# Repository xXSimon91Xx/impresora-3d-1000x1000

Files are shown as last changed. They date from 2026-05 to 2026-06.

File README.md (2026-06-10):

<p align="center">
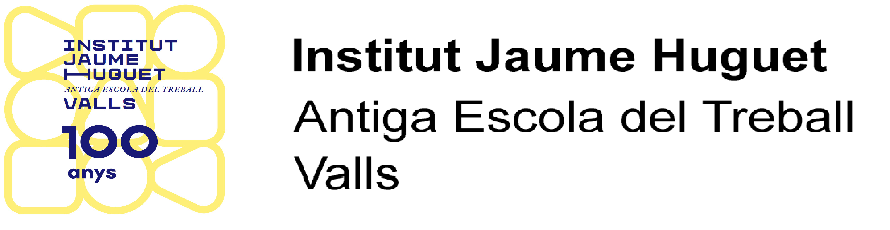
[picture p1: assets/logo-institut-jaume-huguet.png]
Institut Jaume Huguet — Antiga Escola del Treball, Valls
  
</p>

<h1 align="center">Impresora 3D Cartesiana 1000×1000×1000 mm</h1>

<p align="center">
  <strong>Cicle Formatiu de Fabricació Additiva — CEFP 2025-2026</strong><br>
  <strong>Institut Jaume Huguet — Antiga Escola del Treball</strong>, Valls (Tarragona)<br>
  <a href="https://institutjaumehuguet.cat">institutjaumehuguet.cat</a>
</p>

<p align="center">
  
  
  
</p>

---

## Versiones del repositorio

| Idioma | Repositorio |
|---|---|
| 🇪🇸 Español | **este repositorio** |
| 🏴󠁥󠁳󠁣󠁴󠁿 Català | [impresora-3d-1000x1000-ca](https://github.com/xXSimon91Xx/impresora-3d-1000x1000-ca) |
| 🇬🇧 English | [impresora-3d-1000x1000-en](https://github.com/xXSimon91Xx/impresora-3d-1000x1000-en) |

---

## Índice de documentación

### Para empezar — guía de la máquina
- [¿Qué es esta máquina?](#qué-es-esta-máquina) — resumen accesible para todos los niveles
- [El equipo](equipo.md) — alumnos, profesores y agradecimientos
- [Diario del proyecto](diario/progreso.md) — cronología completa desde febrero 2026

### Hardware
- [**Archivos 3D — 57 archivos STEP**](hardware/archivos-3d/) — ensamble completo, extrusor, ejes, cama
- [Lista de materiales — Estructura](hardware/lista-materiales-estructura.md)
- [Planos estructurales — Marco item](hardware/planos-estructurales.md)
- [Placa BTT Octopus Pro](hardware/placa-octopus-pro.md)
- [Motores y drivers](hardware/motores-drivers.md)
- [Piezas impresas en 3D](hardware/piezas-impresas.md)
- **Cableado:**
  - [Visión general — todos los sistemas](hardware/cableado/overview.md)
  - [Eje X](hardware/cableado/eje-x.md) · [Eje Y dual](hardware/cableado/eje-y.md) · [Eje Z dual](hardware/cableado/eje-z.md)
  - [Extrusor Smart Orbiter v3.0](hardware/cableado/extrusor.md)
  - [CR Touch — Sonda Z](hardware/cableado/crtouch.md)
  - [Cama calefactada](hardware/cableado/cama.md)

### Firmware
- [Configuración completa (printer.cfg)](firmware/printer.cfg)
- [Instalación de Klipper en CB1](firmware/klipper-setup.md)
- [Calibración — PID, Z offset, Bed Mesh](firmware/calibracion.md)

### Problemas encontrados y soluciones
- [Índice de problemas](problemas/README.md)

### Ideas de futuro
- [Proyectos y mejoras planificadas](futuro.md)

---

## ¿Qué es esta máquina?

Esta impresora 3D puede fabricar objetos de hasta **1 metro de largo, 1 metro de ancho y 1 metro de alto**. Es una de las impresoras más grandes que se pueden construir con piezas comerciales disponibles.

Se trata de una impresora **cartesiana**: el cabezal de impresión se mueve en los ejes X e Y, y la estructura sube y baja en el eje Z. El material (filamento de plástico) se funde y se deposita capa a capa hasta formar la pieza.

**¿Para qué sirve?** Para fabricar piezas grandes que no caben en una impresora normal: estructuras, moldes, prototipos industriales, piezas de coches, proyectos de arquitectura, etc.

**¿Qué la hace especial?** Todo el sistema de control (firmware Klipper) es de código abierto y se puede acceder a él desde cualquier dispositivo de la red del instituto. No necesita un ordenador conectado para imprimir — tiene su propio ordenador de control integrado (BTT CB1).

---

## La máquina terminada — 5 junio 2026

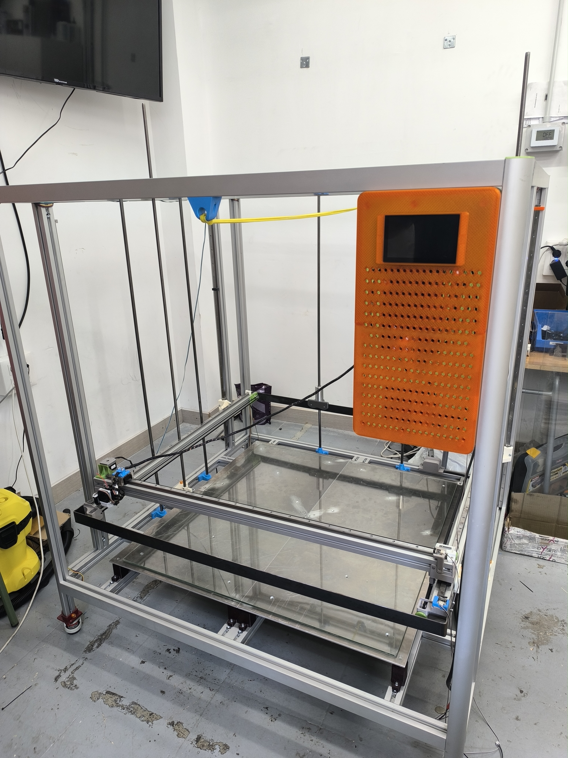
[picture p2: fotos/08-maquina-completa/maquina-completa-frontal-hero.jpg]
Máquina completa

*La impresora 3D de 1000×1000×1000mm completamente ensamblada en el taller del Institut Jaume Huguet. Altura total ~1.5m. KlipperScreen táctil (naranja) montado en el perfil derecho. Cama de cristal provisional instalada.*

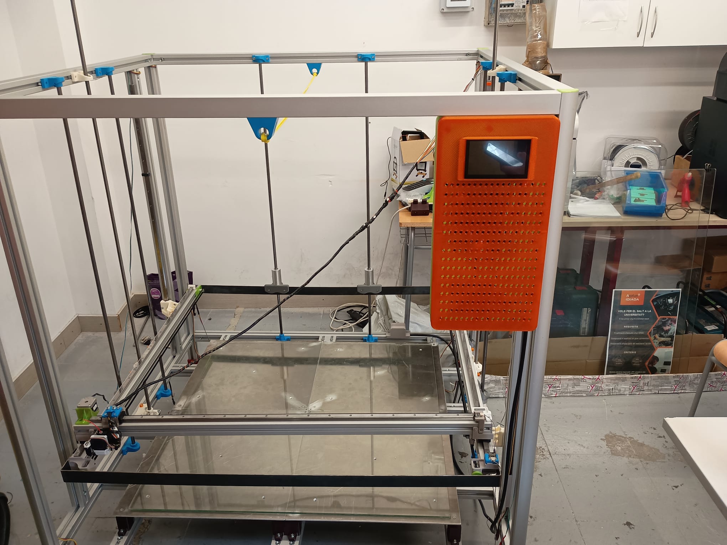
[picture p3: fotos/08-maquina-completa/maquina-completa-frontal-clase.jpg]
Máquina vista frontal con pantalla

*Vista frontal de la impresora en el aula del taller. La escala respecto al mobiliario del instituto da una idea del tamaño de la máquina.*

---

## Fotos del proyecto

### Panel de electrónica instalado — 1 junio 2026

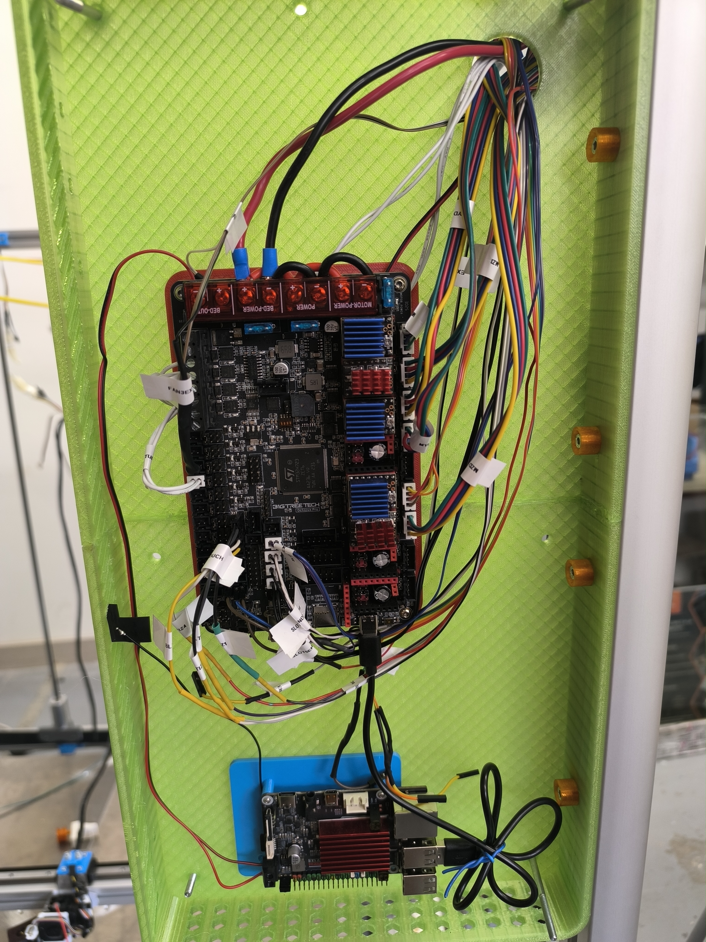
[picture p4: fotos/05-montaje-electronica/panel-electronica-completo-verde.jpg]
Panel electrónica completo

*Panel verde con la BTT Octopus Pro V1.1, el CB1 y todos los cables etiquetados y conectados. El panel se desmonta para mantenimiento.*

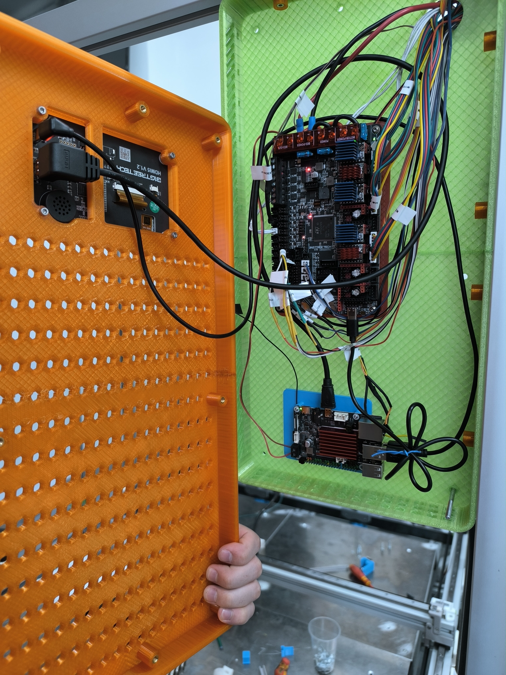
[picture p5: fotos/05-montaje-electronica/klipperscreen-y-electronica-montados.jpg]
KlipperScreen y electrónica montados

*La pantalla táctil KlipperScreen (naranja) junto al panel de electrónica ya instalados en la máquina.*

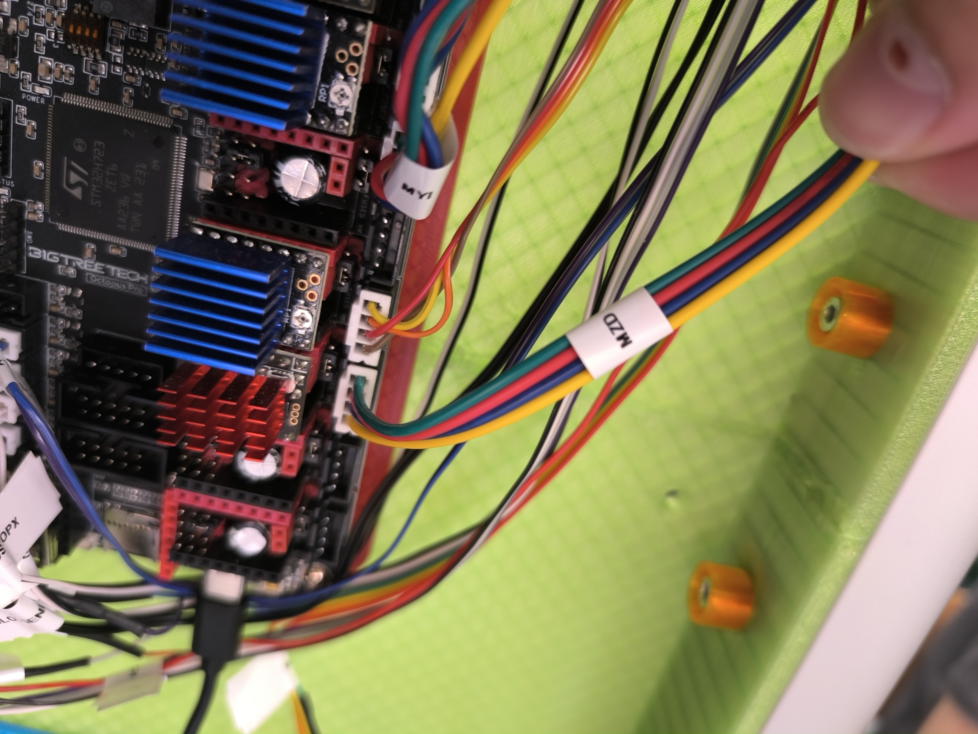
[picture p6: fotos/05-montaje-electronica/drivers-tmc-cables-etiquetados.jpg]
Drivers TMC y cables etiquetados

*Detalle de los drivers TMC2209 (azul) y TMC5160 (rojo) con los cables etiquetados: MY1, MY2, MX, MZ1, MZ2, EXTRUSOR.*

### Primer arranque con Klipper

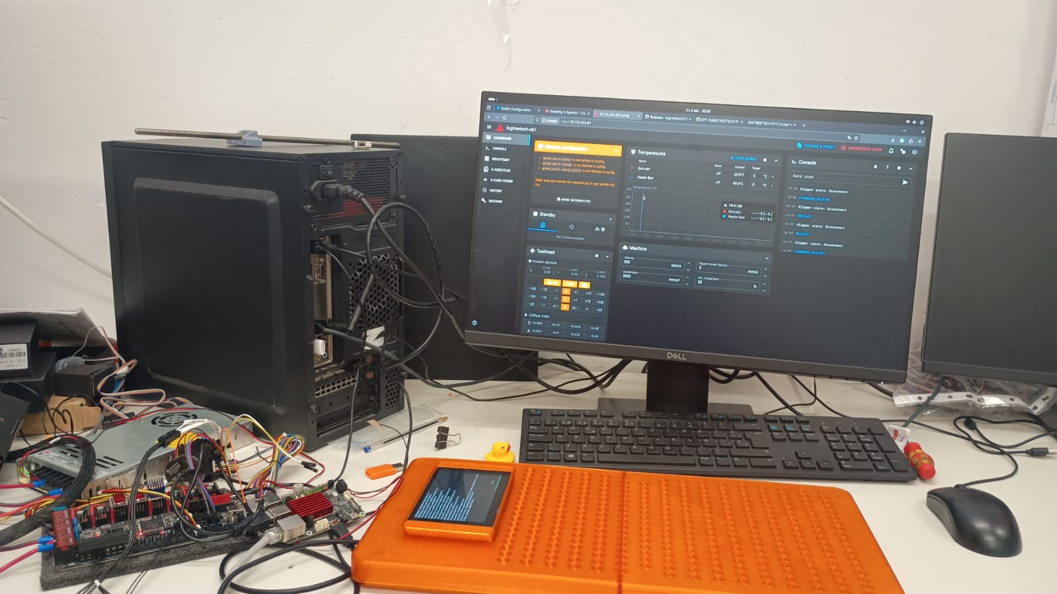
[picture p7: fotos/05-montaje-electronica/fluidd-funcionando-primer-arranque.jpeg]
Fluidd funcionando

*Primer arranque con Fluidd en el monitor Dell, KlipperScreen en pantalla naranja, y toda la electrónica conectada.*

### Placa base — BTT Octopus Pro V1.1

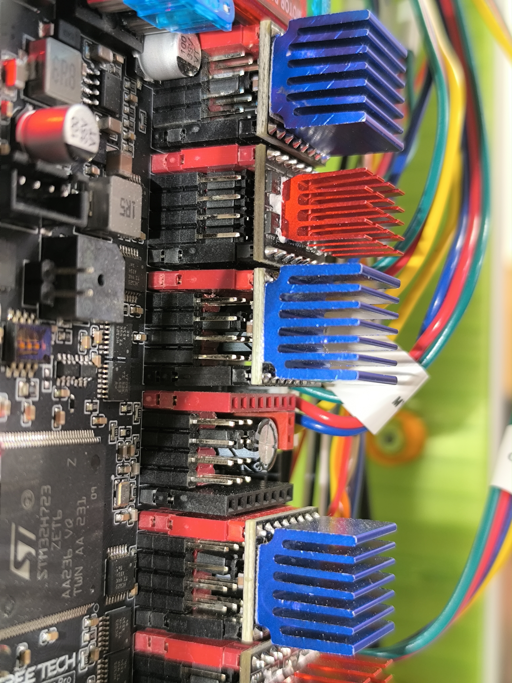
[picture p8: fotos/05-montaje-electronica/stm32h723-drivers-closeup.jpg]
Octopus Pro chip STM32

*Detalle del chip STM32H723 de la Octopus Pro con los drivers TMC5160 (rojo, eje Z) y TMC2209 (azul, ejes XY y extrusor).*

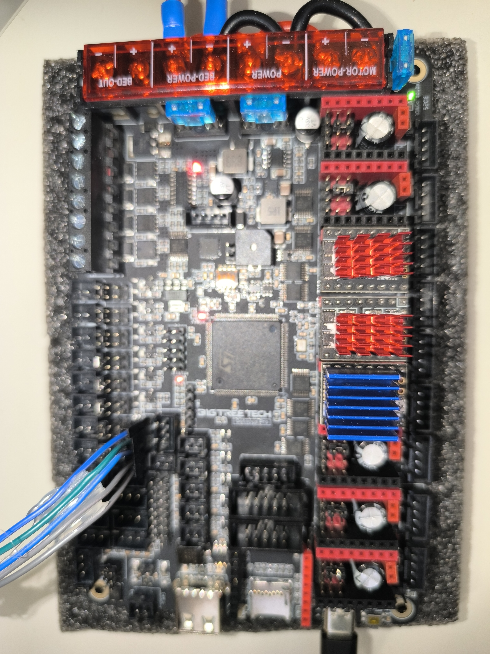
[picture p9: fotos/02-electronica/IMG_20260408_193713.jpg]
Octopus Pro con drivers

*Vista frontal de la BTT Octopus Pro V1.1. TMC5160 rojos para Z (alta corriente), TMC2209 azules para X, Y y extrusor.*

### Estructura y guías lineales

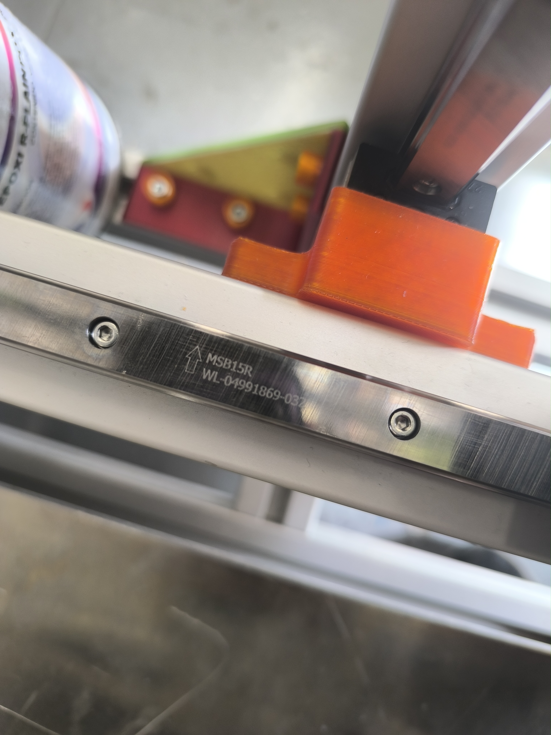
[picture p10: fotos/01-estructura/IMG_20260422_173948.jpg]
Guía lineal

*Guía lineal MGN15R con carro montado sobre perfil item 40×80mm.*

### Piezas impresas en 3D

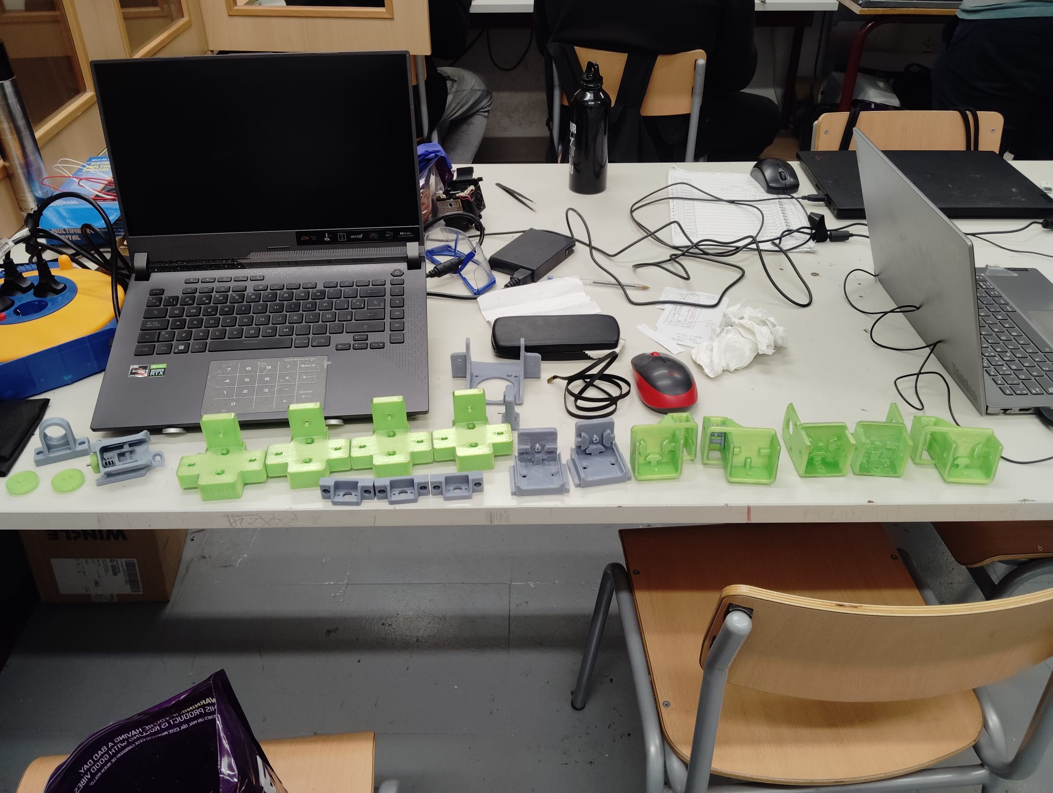
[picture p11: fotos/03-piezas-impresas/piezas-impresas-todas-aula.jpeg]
Piezas en aula

*Todas las piezas impresas antes del montaje: soportes de motor (verde PETG), guías y clips (gris ASA).*

### Planos estructurales — marcos item

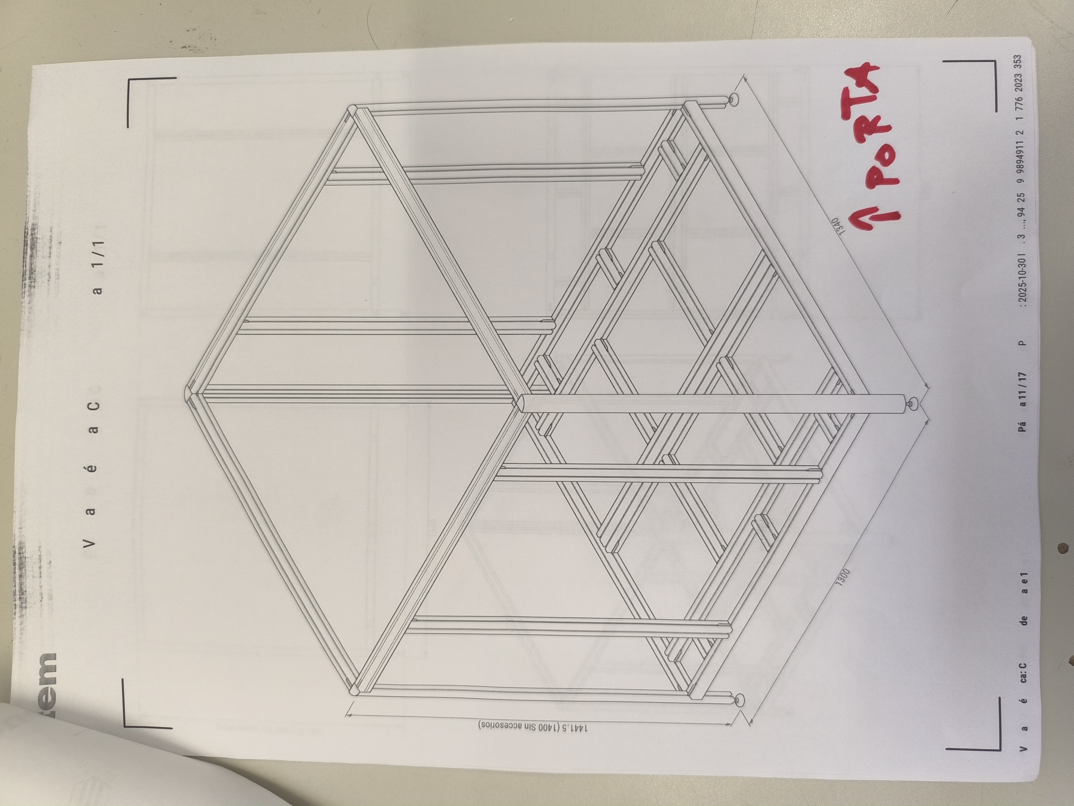
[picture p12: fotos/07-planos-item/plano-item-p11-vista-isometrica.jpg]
Plano item isométrico

*Vista isométrica del marco de aluminio. Planos generados con el configurador de item — 17 páginas.*

---

## Especificaciones técnicas

| Parámetro | Valor |
|---|---|
| **Volumen de impresión** | 1000 × 1000 × 1000 mm |
| **Cinemática** | Cartesiana (ejes X/Y/Z independientes) |
| **Firmware** | Klipper + Fluidd (interfaz web) + KlipperScreen |
| **Placa base** | BigTreeTech Octopus Pro V1.1 (STM32H723) |
| **Ordenador de control** | BigTreeTech CB1 (ARM Cortex-A55, Linux) |
| **Velocidad máxima** | 300 mm/s (XY), 5 mm/s (Z) |
| **Aceleración máxima** | 3000 mm/s² |
| **Extrusor** | LDO Smart Orbiter v3.0 (direct drive, reducción 7.5:1) |
| **Motor extrusor** | LDO-36STH20-1004AHG |
| **Hotend** | Boquilla 0.4 mm, 24V 72W calentador cerámico |
| **Sensor Z** | CR Touch ALT04 (Creality) |
| **Drivers XY/Extrusor** | TMC2209 (UART, StealthChop) |
| **Drivers Z** | TMC5160-T Pro (SPI, alta corriente, 2A) |
| **Motores XY** | NEMA 17 |
| **Motores Z** | NEMA 23 (2 unidades, dual Z independiente) |
| **Guías lineales** | MGN15R (rodamientos recirculantes) |
| **Husillo Z** | M12 × 4 entradas → 8 mm/vuelta |
| **Marco** | Perfiles item 40×80 mm (serie XMS, art. 0.0.669.99) |
| **Piezas mecánicas** | PETG (verde, no crítico) + ASA/ABS (gris, crítico) |

---

## Historia del proyecto

Este proyecto fue diseñado desde el principio como una impresora de **1000×1000×1000 mm**, con el objetivo de que la máquina quede en el **Institut Jaume Huguet** para uso de los alumnos y como referencia para que otros centros puedan replicarla.

Antes de construirla, usamos una impresora de 500×500 mm para validar el firmware y la electrónica — así llegamos a la impresora grande con todo ya probado.

El mayor reto técnico fue el **doble eje Z con NEMA 23**: necesitan 2 A de corriente, lo que obliga a usar drivers TMC5160 (los TMC2209 normales no aguantan). Además, uno de los slots de la placa resultó estar defectuoso de fábrica y hubo que mover el motor al slot MOTOR 5.

El marco está construido con **perfiles item 40×80 mm**, un sistema modular de aluminio técnico usado en maquinaria industrial, lo que garantiza rigidez y precisión incluso a esta escala.

---

*Cicle Formatiu de Fabricació Additiva — CEFP 2025-2026 | Institut Jaume Huguet — Antiga Escola del Treball, Valls*

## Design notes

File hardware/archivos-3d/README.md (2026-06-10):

# Archivos 3D — Impresora 1000×1000×1000mm

Todos los archivos STEP del proyecto. Formato STEP (ISO 10303) — compatible con cualquier software CAD (FreeCAD, Fusion 360, SolidWorks, CATIA, etc.).

> Cicle Formatiu de Fabricació Additiva — CEFP 2025-2026 | Institut Jaume Huguet — Antiga Escola del Treball, Valls.

---

## Ensamble completo

| Archivo | Descripción |
|---|---|
| `Ensamble Impresora gran formato V4.step` | Ensamble completo de la impresora (todos los ejes, marco, extrusor) |
| `Impresora gran formato V4_Estructrura 140.step` | Estructura completa del marco de perfiles item 40×80mm |

---

## Extrusor y cabezal

| Archivo | Descripción |
|---|---|
| `Extrusor orbital V3.0.step` | LDO Smart Orbiter v3.0 — extrusor direct drive completo |
| `Ensamble Soporte carro de bolas PS 2-15 extrusor orbital (eje X) guia superior.step` | Soporte del extrusor sobre el carro del eje X |
| `Soporte carro de bolas PS 2-15 extrusor orbital (eje X) Nuevo (1).step` | Soporte actualizado del carro extrusor |
| `Soporte ventilador de capa Creality DC brushless CHA4024RM-10B con Cr-touch.step` | Soporte ventilador de capa + CR Touch integrado |
| `4010 turbo fan Creality DC Brushless CHA4024RM-10B.step` | Ventilador de capa 40×10mm |
| `Tobera ventilador de capa.step` | Tobera direccional del ventilador de capa |
| `CR-Touch-Dummy v1.step` | Modelo de referencia del CR Touch ALT04 |

---

## Eje X

| Archivo | Descripción |
|---|---|
| `Carro con recirculación de bolas PS 2-15 (eje X).step` | Carro lineal MGN15 eje X |
| `soporte motor eje X_.step` | Soporte del motor NEMA 17 eje X |
| `Soporte nuevo eje X sobre eje Y.step` | Soporte del eje X sobre los carriles del eje Y |
| `Tensor eje X.step` | Tensor de correa GT2 eje X |
| `Tensor correa GT2 eje X con polea dentada.step` | Tensor completo con polea dentada |
| `Eje polea elemento Tensor eje X.step` | Eje del elemento tensor eje X |
| `Elemento polea Tensor eje X.step` | Polea del tensor eje X |
| `Rueda de tensor pequeña eje X.step` | Rueda de tensado eje X |
| `Fijador correa eje X parte fija.step` | Fijador fijo de correa GT2 eje X |
| `Fijador correa eje X parte movil.step` | Fijador móvil de correa GT2 eje X |
| `Motor paso a paso 17H2041-100-4AL-1 eje x.step` | NEMA 17 montado en eje X |
| `item_69468_carril-guia-ps-2-15-6946_1120_high.step` | Carril guía lineal PS 2-15 (1120mm) eje X |

---

## Eje Y

| Archivo | Descripción |
|---|---|
| `soporte motores nema 17 eje Y derecha.step` | Soporte motor NEMA 17 eje Y lado derecho |
| `soporte motores nema 17 eje Y Izquierda.step` | Soporte motor NEMA 17 eje Y lado izquierdo |
| `soporte tensor eje Y (derecho).step` | Tensor de correa GT2 eje Y lado derecho |
| `soporte tensor eje Y (izquierdo).step` | Tensor de correa GT2 eje Y lado izquierdo |
| `soporte tensor eje Y (derecho) cuerpo.step` | Cuerpo del tensor eje Y derecho |
| `soporte tensor eje Y (izquierdo) cuerpo.step` | Cuerpo del tensor eje Y izquierdo |
| `Brazo soporte tensor eje Y.step` | Brazo articulado del tensor eje Y |
| `eje de rotación brazo soporte tensor eje Y.step` | Eje de rotación del brazo tensor |
| `eje de tensión brazo soporte tensor eje Y.step` | Eje de tensión del brazo tensor |
| `eje polea libre brazo soporte tensor eje Y.step` | Eje de la polea libre del brazo tensor |
| `Rueda de tensor eje Y.step` | Rueda de tensado eje Y |
| `Fijador correa GT2 eje Y parte inferior.step` | Fijador inferior de correa GT2 eje Y |
| `Fijador correa GT2 eje Y superior.step` | Fijador superior de correa GT2 eje Y |
| `Soporte guia lineal para Perfil 40x40 ejes Y en eje Z.step` | Soporte de guías Y sobre el eje Z |
| `Motor paso a paso 17H2041-100-4AL-1.step` | NEMA 17 estándar eje Y |
| `item_44332_carril-guia-ps-4-15-4433_1060_high.step` | Carril guía PS 4-15 (1060mm) eje Y |
| `item_44332_carril-guia-ps-4-15-4433_1150_high.step` | Carril guía PS 4-15 (1150mm) eje Y |

---

## Eje Z (husillo)

| Archivo | Descripción |
|---|---|
| `motor nema 23 eje Z.step` | Motor NEMA 23 eje Z (2A, alta corriente) |
| `Soporte motor eje Z.step` | Soporte del motor NEMA 23 en el marco |
| `Husillo 8x2 mm 1200mm eje Z.step` | Husillo trapezoidal eje Z (1200mm) |
| `tuerca husillo M8.step` | Tuerca anti-backlash del husillo |
| `Soporte tuerca husillo 8mm.step` | Soporte de la tuerca del husillo |
| `acople 8mm a eje 6,5 motor nema23.step` | Acoplador flexible motor-husillo |

---

## Cama calefactada

| Archivo | Descripción |
|---|---|
| `PLACAS ALUMINIO 500X500.step` | Placa de aluminio 500×500mm (×4 para la cama completa) |
| `Separador cama caliente.step` | Separador simple de cama caliente |
| `Separador doble cama caliente.step` | Separador doble de cama caliente |
| `Separador cuadruple cama caliente.step` | Separador cuádruple de cama caliente |
| `Separador doble cuatro fijaciones.step` | Separador doble con cuatro puntos de fijación |
| `Nivelador TPU cama caliente.step` | Nivelador flexible de TPU para cama caliente |
| `Carro recirculación bolas PS 4-15.step` | Carro lineal PS 4-15 soporte de cama |

---

## Estructura y perfiles item

| Archivo | Descripción |
|---|---|
| `item_44303_perfil-tuerca-8-al-m4-60_1060_high.step` | Tuerca deslizante item M4 (perfil 1060mm) |
| `item_44303_perfil-tuerca-8-al-m4-60_1150_high.step` | Tuerca deslizante item M4 (perfil 1150mm) |

---

## Poleas, rodamientos y elementos de transmisión

| Archivo | Descripción |
|---|---|
| `GT2 polea dentada-20T-5mm agujero-correa 6mm-tornillo.step` | Polea dentada GT2 20T, eje 5mm, correa 6mm |
| `Polea Gt2-20d Libre.step` | Polea GT2 20T libre (sin eje fijo) |
| `Rodamiento de bolas de contacto radial con 2 juntas - para eje Ø8_608EEC3.step` | Rodamiento 608-2RS eje 8mm |
| `Soporte para rodamiento 8mm_.step` | Soporte impreso para rodamiento 8mm |

---

## Software recomendado para visualizar estos archivos

- **FreeCAD** (gratuito, Windows/Linux/Mac) — abre STEP nativamente
- **Fusion 360** (gratuito estudiantes) — importa STEP
- **STEP Viewer online** — [3dviewer.net](https://3dviewer.net) (sin instalación)

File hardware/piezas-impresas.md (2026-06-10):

# Piezas impresas en 3D

> Todos los soportes y piezas mecánicas de la impresora están impresos en 3D. Esto permite adaptar cada pieza exactamente al diseño sin depender de piezas comerciales difíciles de encontrar.

---

## Materiales de impresión

| Material | Color | Uso |
|---|---|-----|
| PETG | Verde | Piezas estructurales no críticas (escuadras, soportes, protectores de barra, topes) |
| ASA / ABS | Gris | Piezas críticas que requieren mayor resistencia (guías de husillo, portacables funcionales) |

---

## Catálogo de piezas

### Soportes de motor NEMA 23 — ×4

Grandes soportes verdes que alojan los motores NEMA 23 de los ejes X e Y. Tienen espacio para el motor, el acoplador y la correa GT2.

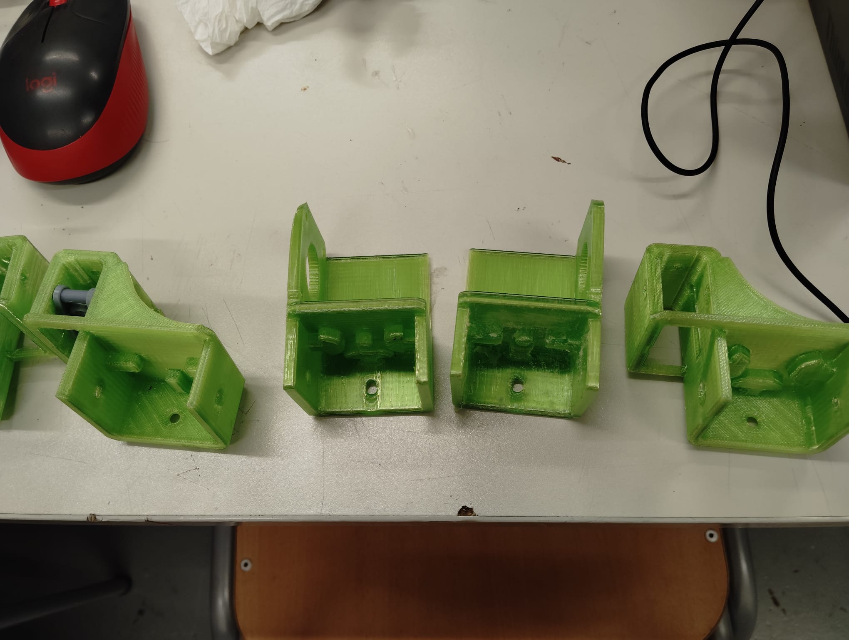
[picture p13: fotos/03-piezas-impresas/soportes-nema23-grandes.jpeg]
Soportes NEMA23

*Cuatro soportes para los motores NEMA 23 de los ejes X e Y.*

---

### Conectores de perfil de aluminio

Conectores metálicos que unen los perfiles de aluminio item 40×80mm entre sí y anclan las guías lineales (ejes X/Y y Z) al marco. No son piezas impresas — son conectores comerciales de acero/aluminio.

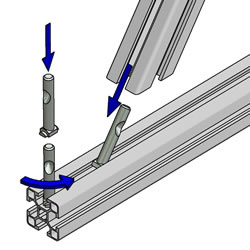
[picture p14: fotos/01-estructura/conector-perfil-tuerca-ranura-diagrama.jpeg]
Diagrama montaje tuerca-ranura

*Diagrama de montaje: la tuerca deslizante entra en la ranura del perfil item 40×80mm y el tornillo la aprieta desde dentro.*

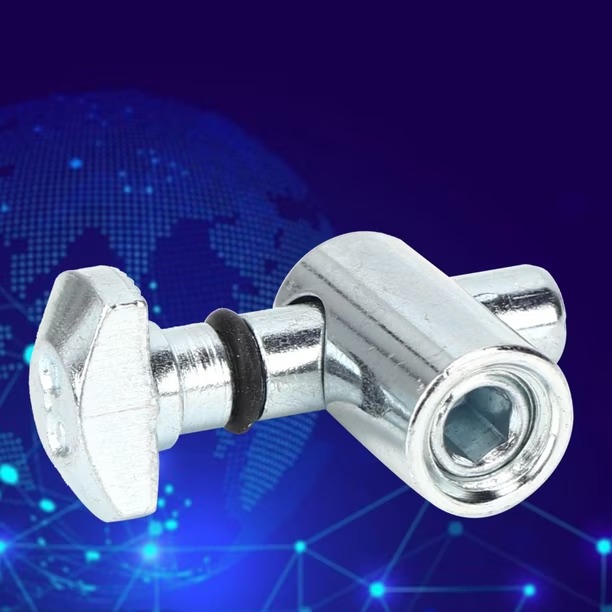
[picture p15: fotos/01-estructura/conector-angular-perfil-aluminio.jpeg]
Conector angular perfil

*Conector angular metálico para unir dos perfiles de aluminio en ángulo recto.*

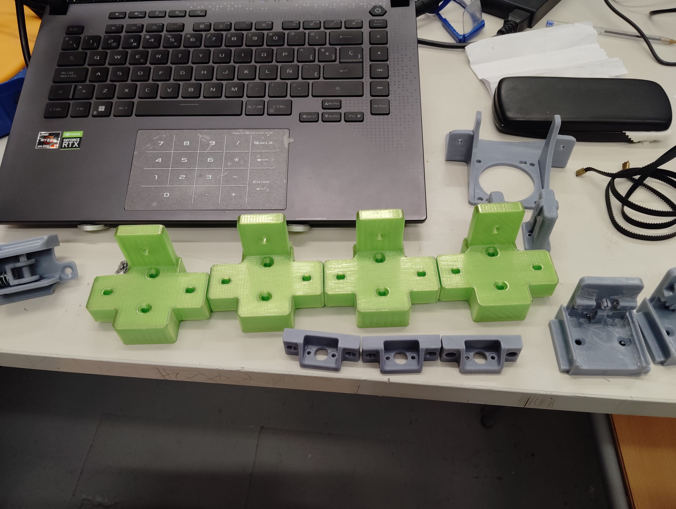
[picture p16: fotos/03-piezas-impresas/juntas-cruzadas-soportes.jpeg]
Soportes varios

*Soportes de correa GT2 y tensores.*

---

### Guías y soportes de husillo (grises)

Piezas grises que sujetan el husillo trapezoidal M12 y lo mantienen alineado con el marco.

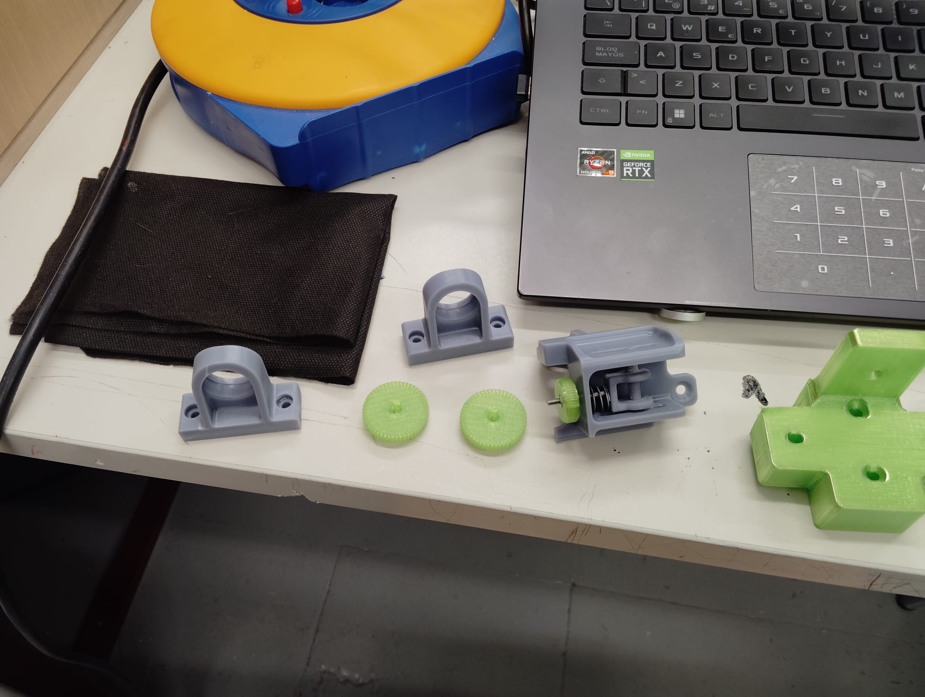
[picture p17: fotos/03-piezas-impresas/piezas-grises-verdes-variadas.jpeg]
Piezas variadas

*Sujetadores de husillo, engranajes de calibración y soporte de endstop.*

---

### Soportes de motor para el eje correa (tensores)

Piezas verdes con ranuras para ajustar la tensión de la correa GT2 de los ejes X e Y.

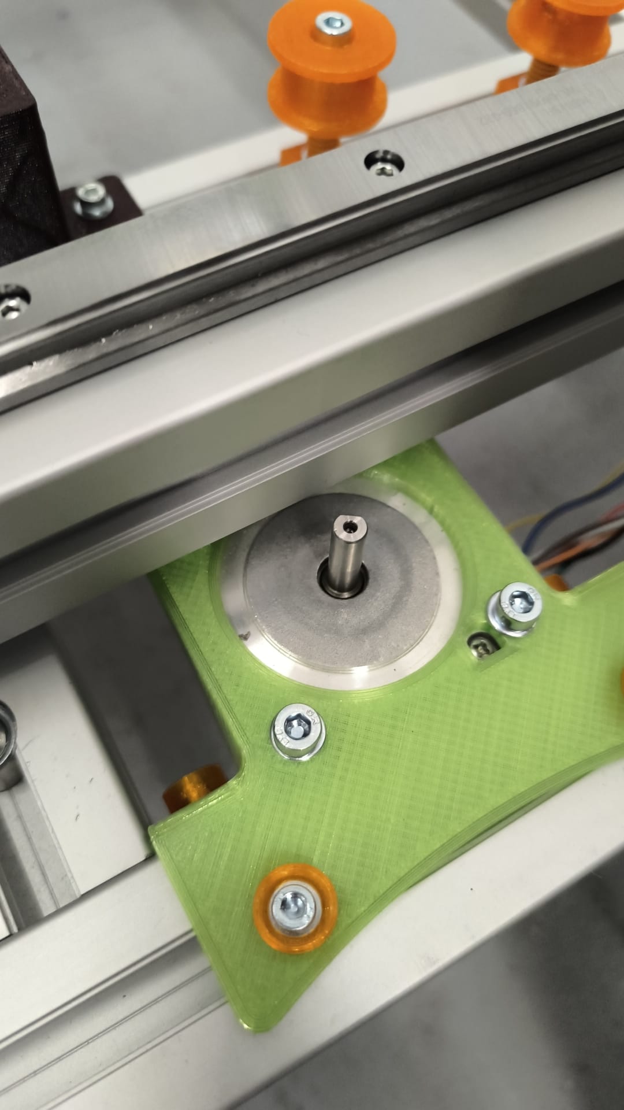
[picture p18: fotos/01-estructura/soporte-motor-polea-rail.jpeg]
Soporte motor polea

*Soporte de motor con polea metálica montado sobre el perfil de aluminio.*

---

### Portacables y organizadores

Piezas grises pequeñas que guían los cables por el marco y los mantienen ordenados.

---

## Todas las piezas en el aula

Piezas en aula
*Vista completa de todas las piezas impresas antes del montaje. Las verdes son estructurales, las grises son auxiliares.*

Piezas en aula completo
*Vista más amplia: toda la gama de piezas extendida en la mesa del aula — soportes de motor, portacables, tensores de correa y guías.*

Soportes NEMA23 alineados
*Los cuatro soportes de motor NEMA 23 (verde) alineados. El diseño en U permite alojar el motor, el acoplador y la parte superior del husillo.*

Tensores y portacables
*Tensores de correa GT2 verdes, portacables grises y soporte de motor. Al fondo se ve la correa GT2.*

Piezas grises detalle
*Piezas auxiliares grises: portacables, engranajes de calibración y soporte de sensor de filamento montado.*

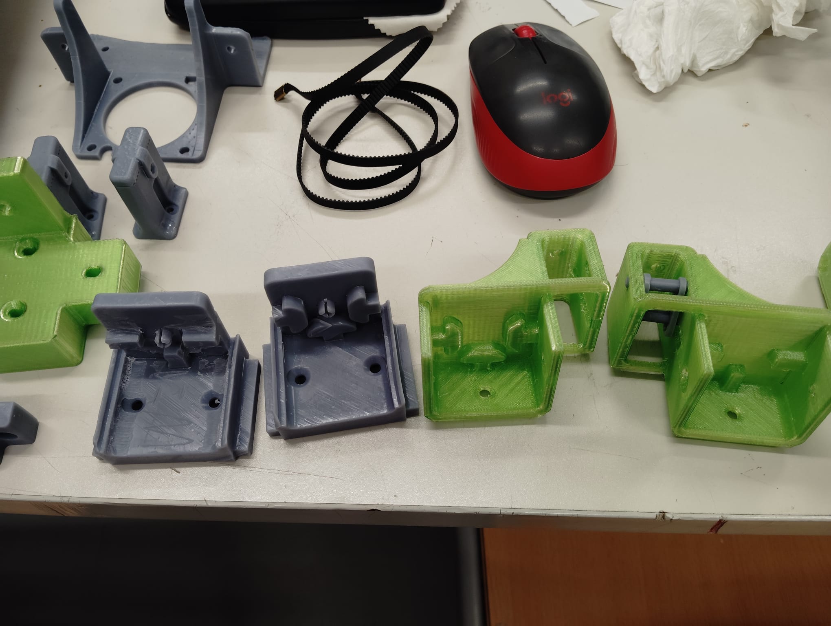
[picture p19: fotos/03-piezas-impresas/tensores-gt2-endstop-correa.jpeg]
Tensores GT2 y endstop

*Tensores de correa GT2 (verde), soporte de endstop (gris), y la correa GT2 de 6mm de paso 2mm. También se ven los soportes de ventilador y el carril guía.*

---

## Render del sistema de tensado de correas

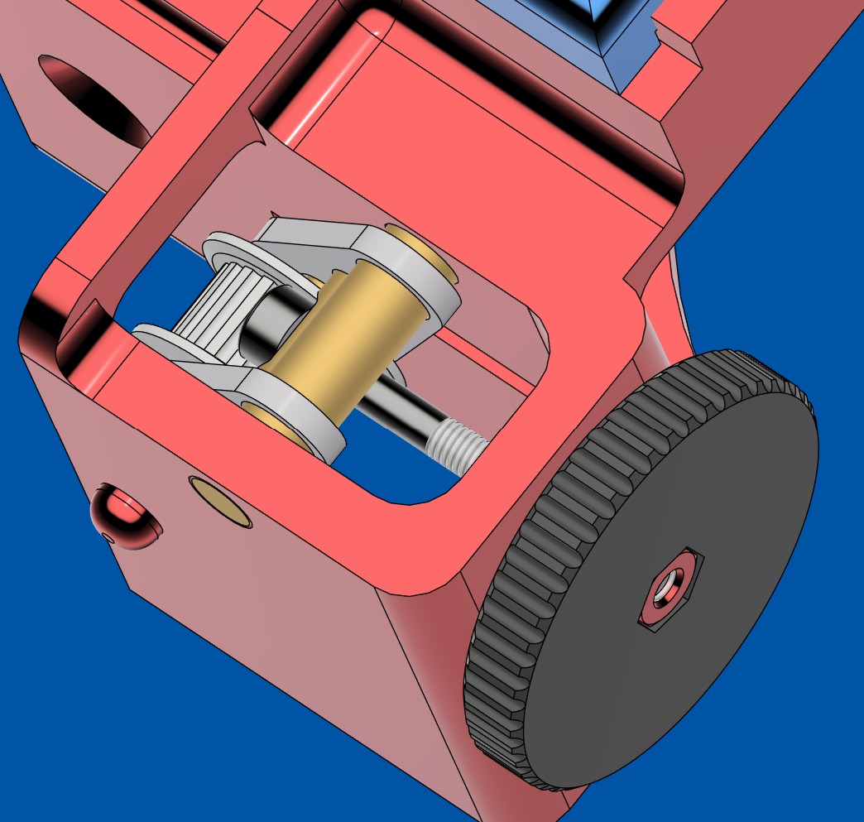
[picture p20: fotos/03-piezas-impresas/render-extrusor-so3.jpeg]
Render tensado correas

*Renderizado 3D del sistema de tensado de correas GT2 de los ejes X e Y, mostrando el mecanismo de ajuste de tensión.*

---

## Patas niveladoras con bloqueo

La estructura descansa sobre **4 ruedas niveladoras** con bloqueo. Permiten mover la impresora fácilmente y fijarla cuando está en posición.

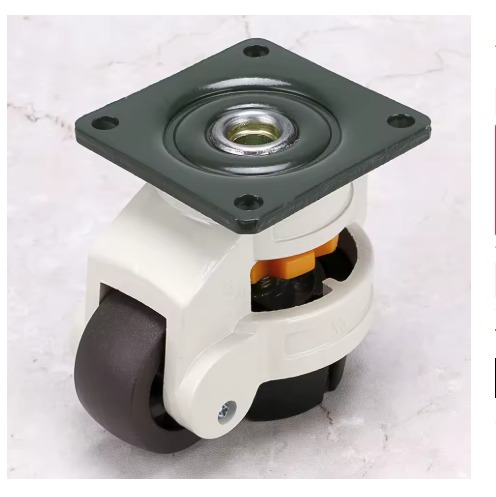
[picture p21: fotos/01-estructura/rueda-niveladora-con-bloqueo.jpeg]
Rueda niveladora

*Rueda niveladora con mecanismo de bloqueo. El botón naranja baja un apoyo metálico que levanta la rueda del suelo, inmovilizando la máquina.*

---

## Mejoras futuras planificadas

### Cierre con paneles de policarbonato

Para poder imprimir materiales técnicos (ABS, ASA, TPU) que necesitan temperatura ambiente estable, se planea cerrar la máquina con paneles de policarbonato corrugado fijados con **imanes de neodimio**.

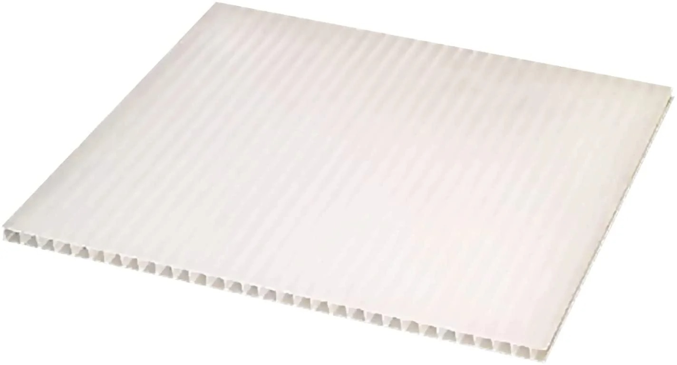
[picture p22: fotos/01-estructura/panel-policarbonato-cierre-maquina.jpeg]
Panel policarbonato

*Panel corrugado de policarbonato — ligero, resistente y fácil de cortar a medida.*

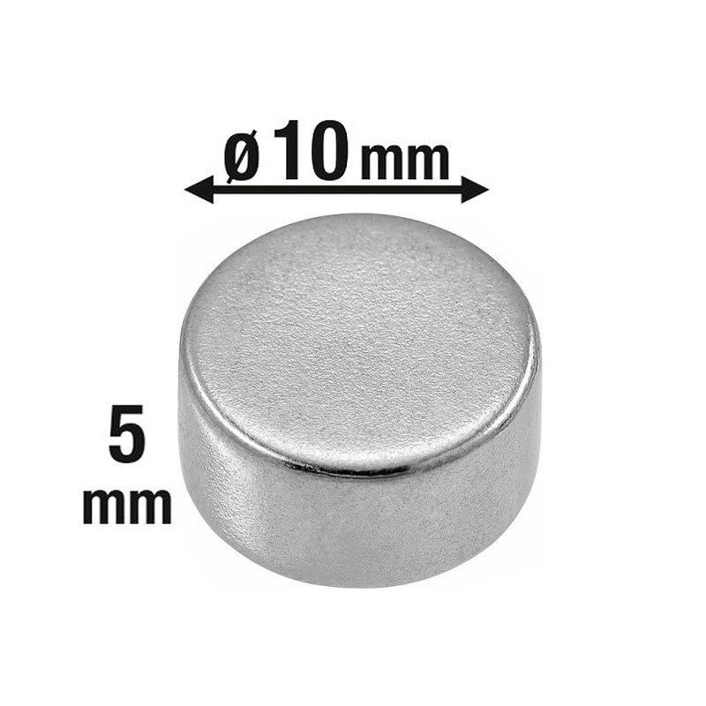
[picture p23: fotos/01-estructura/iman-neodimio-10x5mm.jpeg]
Imán neodimio

*Imán de neodimio ø10×5mm — embutido en las piezas impresas para retener los paneles sin tornillos.*

Los paneles se fijan sin tornillos: los imanes van embutidos en piezas impresas del marco y en el borde del panel, permitiendo abrirlos y cerrarlos rápidamente.

---

## Archivos 3D

Los archivos STEP de todos los componentes del proyecto están disponibles en la carpeta [`hardware/archivos-3d/`](archivos-3d/).

Incluye: ensamble completo, extrusor Smart Orbiter v3.0, ejes X/Y/Z, cama calefactada, perfiles item y elementos de transmisión (57 archivos STEP en total).

Formato STEP — compatible con FreeCAD, Fusion 360, SolidWorks y cualquier CAD estándar. También visualizables online en [3dviewer.net](https://3dviewer.net).

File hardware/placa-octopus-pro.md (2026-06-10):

# BTT Octopus Pro V1.1 — Guía de configuración

> Placa base del proyecto. Controla todos los motores, sensores, calefactores y ventiladores.

---

## Vista general

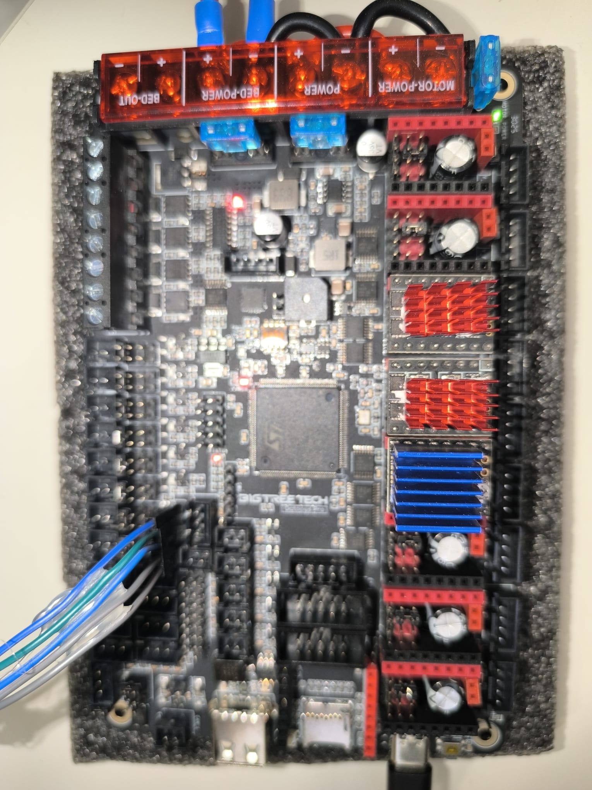
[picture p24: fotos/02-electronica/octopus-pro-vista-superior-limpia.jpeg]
Octopus Pro V1.1 vista superior

*Vista superior de la Octopus Pro V1.1 sin cables: se ven todos los slots de driver, los conectores de alimentación (MOTOR-POWER, POWER, BED-POWER) y los terminales de motor.*

Octopus Pro V1.1 overview
*Octopus Pro V1.1 con los 8 slots de driver ocupados: TMC5160 (rojos) para Z, TMC2209 (azules) para X, Y y extrusor.*

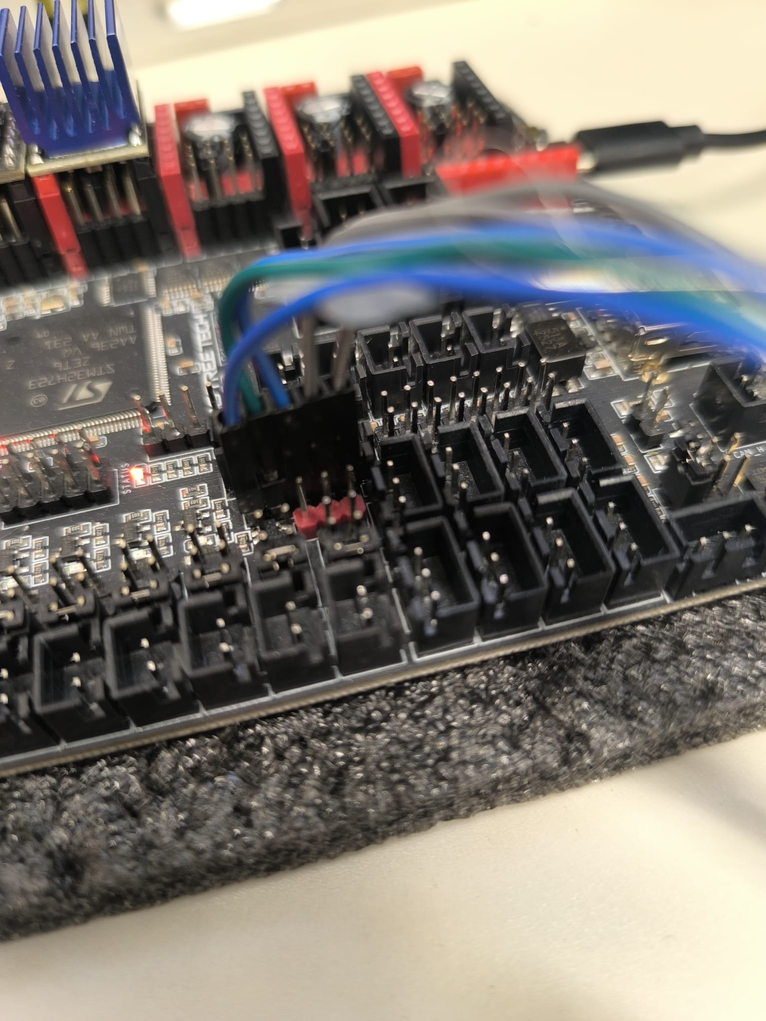
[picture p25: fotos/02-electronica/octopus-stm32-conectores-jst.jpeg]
STM32H723 closeup

*Closeup del microcontrolador STM32H723 y los conectores JST de motor. Se puede leer claramente el chip "STM32H723ZET6" de ST Microelectronics.*

---

## Especificaciones

| Campo | Valor |
|---|---|
| **MCU** | STM32H723ZET6 (ARM Cortex-M7 @ 550MHz) |
| **Slots de driver** | 8 (MOTOR 0 → MOTOR 7) |
| **Hotend heaters** | 4 (HE0–HE3) |
| **Cama** | 1 salida dedicada (BED-OUT) |
| **Ventiladores** | 6 PWM + 2 siempre-on |
| **Termistores** | 4 (T0–T3) + 2 PT100/PT1000 |
| **Endstops** | 6 + soporta sensores virtuales |
| **Firmware** | Klipper, Marlin, RRF |
| **Conexión CB1** | USB-C (montaje directo o cable) |

---

## Slots de driver — Asignación en nuestro proyecto

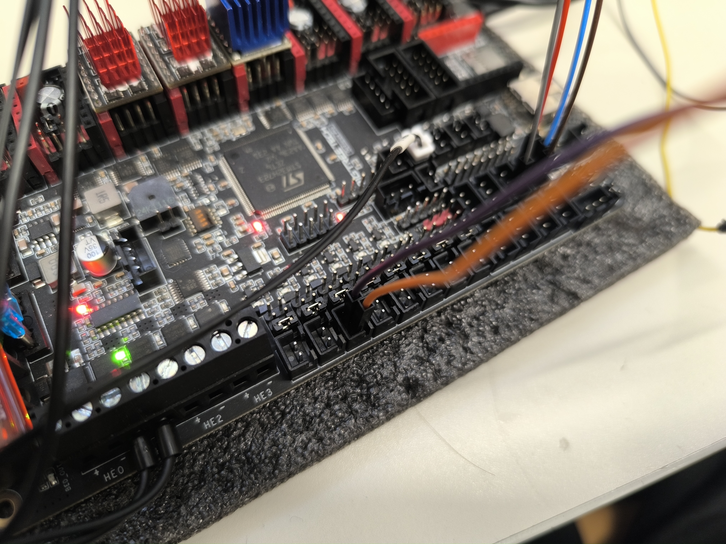
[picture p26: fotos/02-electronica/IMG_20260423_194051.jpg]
Placa con cableado

*Vista de los 8 slots con drivers instalados y cables de motor conectados. Los rojos son TMC5160 (Z), los azules son TMC2209.*

| Slot | Componente | Driver | Estado |
|---|---|---|---|
| MOTOR 0 | Eje X | TMC2209 azul | ✅ Activo |
| MOTOR 1 | Eje Z izquierdo | TMC5160 rojo | ✅ Activo |
| MOTOR 2_1 | Eje Y (dual paralelo) | TMC2209 azul | ✅ Activo |
| MOTOR 2_2 | Motor Y derecho (paralelo físico) | — | ✅ Activo |
| MOTOR 3 | — | — | ❌ **DEFECTUOSO** |
| MOTOR 4 | Extrusor SO3 | TMC2209 azul | ✅ Activo |
| MOTOR 5 | Eje Z derecho | TMC5160 rojo | ✅ Activo |
| MOTOR 6-7 | Libres | — | — |

---

## Protocolo de drivers: UART vs SPI

La placa soporta ambos protocolos simultáneamente:

### UART (TMC2209)
- 1 solo cable de datos por driver
- Configuración más simple
- Máx. ~1.5A continuo

```ini
# Ejemplo UART (eje X)
[tmc2209 stepper_x]
uart_pin: PC4    # Pin UART único por driver
```

### SPI (TMC5160)
- 4 cables compartidos (MISO/MOSI/SCK) + 1 Chip Select por driver
- Mayor corriente posible (hasta 3A RMS)
- Telemetría más detallada

```ini
# Ejemplo SPI (eje Z)
[tmc5160 stepper_z]
cs_pin: PD11                    # Chip Select único
spi_software_miso_pin: PA6      # Compartido entre todos los TMC5160
spi_software_mosi_pin: PA7
spi_software_sclk_pin: PA5
```

---

## Jumpers de voltaje — Configuración crítica

La Octopus Pro tiene jumpers para configurar el voltaje de cada slot de driver. Para TMC5160 es **obligatorio** ponerlos correctamente:

- **TMC5160:** Jumper en posición `VFused` (voltaje de motor, no 5V)
- **TMC2209:** Jumper en posición `VFused` también

> Error frecuente: Jumper mal puesto en un slot con TMC5160 → el driver no recibe suficiente tensión → el motor no se mueve o se mueve erráticamente.

---

## Alimentación

La placa tiene **tres entradas de alimentación independientes**:

```
┌─────────────────────────────────────────────────────┐
│  MOTOR-POWER ────── 24V/12-60V para todos los drives  │
│  POWER       ────── 24V para lógica y calefactores    │
│  BED-POWER   ────── 24V para la cama calefactada      │
└─────────────────────────────────────────────────────┘
```

Mantener BED-POWER separado es importante: la cama consume mucha corriente y puede introducir ruido en las señales de paso si comparte el rail con los motores.

### Nuestra configuración actual

En este proyecto hemos **puenteado las tres entradas** de alimentación entre sí para simplificar el cableado y poder usar una sola fuente de alimentación 24V.

> **Mejora futura:** Separaremos la entrada `BED-POWER` para conectar un **relé de alta potencia** que gestionará las 4 camas calefactadas de 500×500mm. El relé permite controlar grandes corrientes (>20A) que el MOSFET integrado de la placa no puede manejar directamente.

---

## Conectores de temperatura (T0–T3)

Los conectores T de la placa sirven primariamente para termistores, pero son entradas digitales de 2 pines. En nuestro proyecto:

| Conector | Uso normal | Nuestro uso |
|---|---|---|
| T0 (PF4) | Termistor hotend | Termistor ATC Semitec SO3 |
| T1 (PF5) | Endstop X (reconvertido) | Final de carrera eje X |
| T2 (PF6) | Endstop Y (reconvertido) | Final de carrera eje Y |
| T3 (PF7) | Libre | Endstop Z máximo de seguridad |
| BED (PF3) | Termistor cama | Termistor cama (pendiente) |

---

## Arquitectura del sistema — Dos placas

El sistema usa **dos placas diferenciadas**:

| Placa | Función |
|---|---|
| **BTT Octopus Pro** (MCU STM32H723) | Controla motores paso a paso, temperatura, cama calefactada y ventiladores en tiempo real |
| **BTT CB1** (ARM Cortex-A55, Linux) | El "ordenador": WiFi, interfaz web Fluidd, pantalla KlipperScreen, acceso remoto desde cualquier dispositivo |

El CB1 corre Klipper en Linux y envía comandos al STM32 de la Octopus Pro por USB. El usuario controla todo desde Fluidd (navegador web) o desde la pantalla táctil KlipperScreen.

## Conexión con CB1

El BTT CB1 monta directamente sobre la Octopus Pro (interfaz M.2 o similar). La comunicación se hace por USB-C. Klipper en el CB1 habla con el firmware en el STM32 de la Octopus Pro por ese canal.

Para identificar el puerto serie correcto:
```bash
ls /dev/serial/by-id/
# Resultado: usb-Klipper_stm32h723xx_15000F001051313531383332-if00
```

Este ID se usa en `printer.cfg`:
```ini
[mcu]
serial: /dev/serial/by-id/usb-Klipper_stm32h723xx_15000F001051313531383332-if00
```

---

## Recursos oficiales

- [Repositorio GitHub BTT Octopus Pro](https://github.com/bigtreetech/BIGTREETECH-OCTOPUS-Pro)
- [Manual PDF oficial BTT](https://github.com/bigtreetech/BIGTREETECH-OCTOPUS-Pro/blob/master/BIGTREETECH%20Octopus%20Pro%20V1.0%20user%20manual.pdf)
- [Guía de referencia 3DPrinters-Guide](https://3dprinters-guide.com/bigtreetech-octopus-pro-v1-1-h723-review-a-deep-dive-into-high-speed-3d-printing/)

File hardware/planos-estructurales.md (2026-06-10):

# Planos estructurales — Marco de aluminio item

> Los perfiles de aluminio del marco son de la marca **item** (Industrietechnik GmbH), fabricante alemán especializado en perfiles de aluminio técnico para maquinaria industrial.

---

## Especificaciones del perfil

| Parámetro | Valor |
|---|---|
| **Marca** | item Industrietechnik |
| **Serie** | Perfil X 8 (ranura 8 mm) |
| **Tipo** | R40-90° — XMS, natural |
| **N.° de artículo** | 0.0.669.99 |
| **Sección** | 40 × 80 mm |
| **Longitud de corte** | 1400 mm (dimensión exterior del marco 1441.5 mm con accesorios) |
| **Mecanizado** | Taladro D6.8 con rosca M8 en cara frontal |
| **Material** | Aluminio 6060-T66, anodizado natural |

---

## Planos del proyecto (17 páginas)

Los planos completos del proyecto fueron elaborados con el software de item y comprenden **17 páginas** con especificaciones de perfiles, lista de materiales, guía de instalación paso a paso y vistas técnicas.

### Vistas generales del marco

Vista isométrica — página 11
*Página 11/17: Vista isométrica del marco completo. Dimensión exterior: 1441.5 mm (1400 mm sin accesorios).*

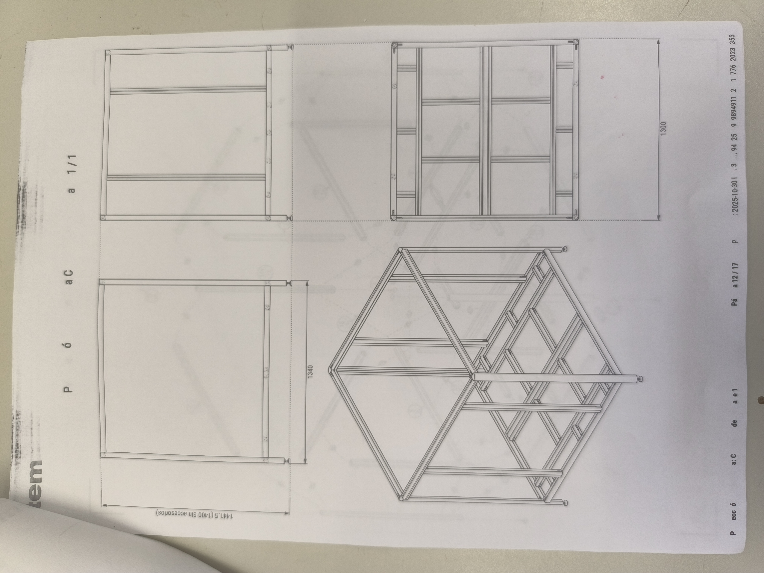
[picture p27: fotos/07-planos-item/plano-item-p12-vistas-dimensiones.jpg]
Vistas y dimensiones — página 12

*Página 12/17: Vistas frontal, lateral y alzado con cotas principales (1300 mm alto, 1340 mm ancho).*

### Lista de materiales y explosionado

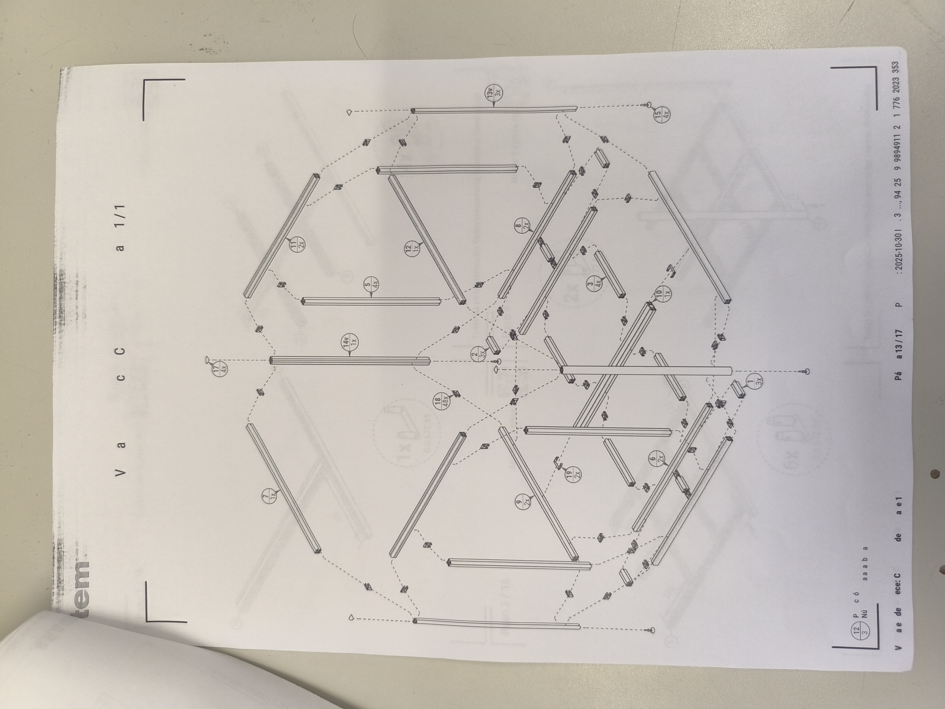
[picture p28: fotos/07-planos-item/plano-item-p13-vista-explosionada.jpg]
Vista explosionada — página 13

*Página 13/17: Vista explosionada mostrando todos los perfiles individuales y sus uniones. Cada perfil tiene un número de posición que referencia la BOM.*

### Especificaciones de perfiles

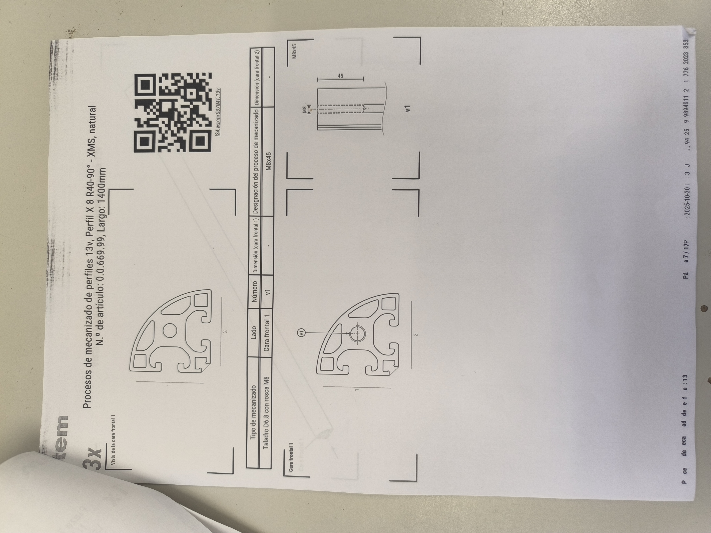
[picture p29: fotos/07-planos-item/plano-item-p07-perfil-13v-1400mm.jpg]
Perfil 13v — página 7

*Página 7/17: Especificación del perfil tipo "13v" — 3 unidades, 1400 mm. Taladro M8 en cara frontal 1.*

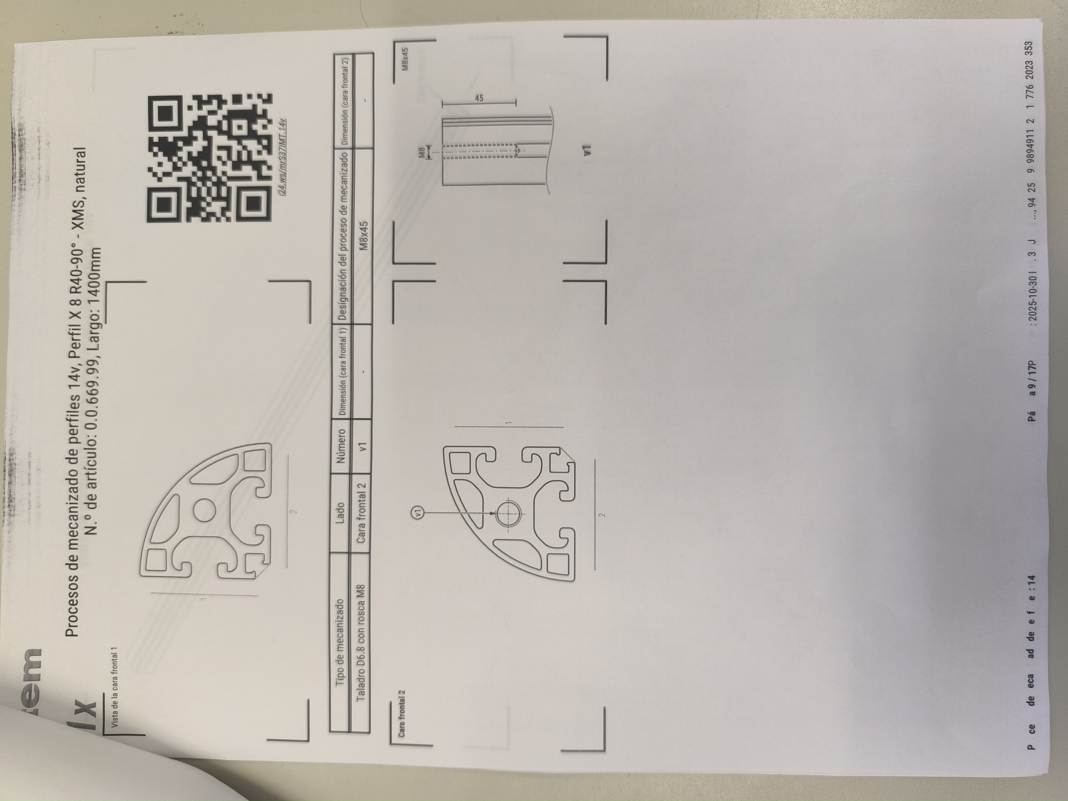
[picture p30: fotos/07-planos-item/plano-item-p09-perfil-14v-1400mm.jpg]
Perfil 14v — página 9

*Página 9/17: Especificación del perfil tipo "14v" — 1 unidad, 1400 mm. Taladro M8 en cara frontal 2.*

### Guía de instalación

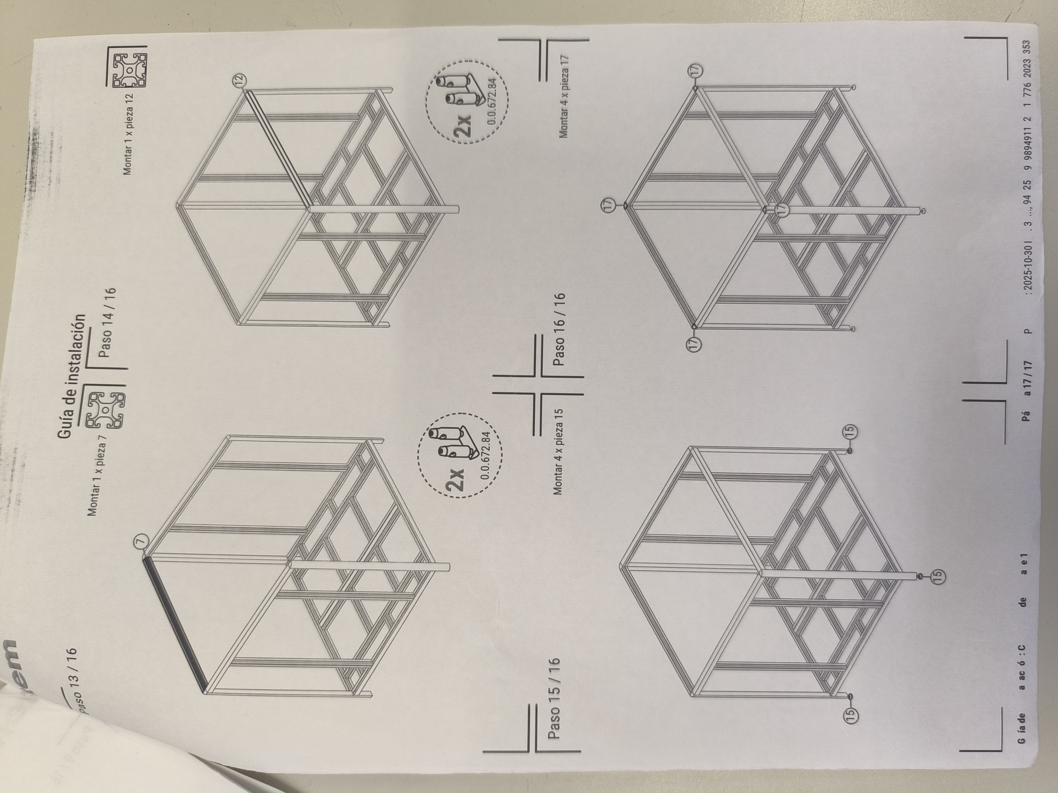
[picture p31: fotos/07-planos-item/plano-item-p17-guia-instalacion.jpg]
Guía instalación — página 17

*Página 17/17: Pasos 13-16 de la guía de instalación. Ítem 0.0.672.84 = conector angular de esquina (2 unidades por paso).*

---

## Conectores y tornillería item

| Componente | N.° artículo item | Descripción |
|---|---|---|
| Conector angular | 0.0.672.84 | Ángulo de 90° para unir perfiles en esquinas |
| Tuerca T ranura 8 | — | M4/M5/M8 según aplicación |
| Tornillo de cabeza cilíndrica | — | M8 × 45 mm para conectores de esquina |

---

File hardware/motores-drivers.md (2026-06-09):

# Motores y Drivers — Por qué elegimos cada uno

> Esta sección explica la elección de motores y drivers para cada eje, con el razonamiento técnico detrás de cada decisión.

---

## Resumen rápido

| Eje | Motor | Driver | Corriente | Protocolo |
|-----|---|---|---|---|
| X | NEMA 17 | TMC2209 | 0.6A run | UART |
| Y (×2 en paralelo) | NEMA 17 | TMC2209 | 1.0A run | UART |
| Z izquierdo | NEMA 23 | TMC5160-T | 2.0A run | SPI |
| Z derecho | NEMA 23 | TMC5160-T | 2.0A run | SPI |
| Extrusor | LDO-36STH20 | TMC2209 | 0.85A run | UART |

---

## TMC2209 vs TMC5160 — ¿Cuándo usar cada uno?

### TMC2209 (UART)

```
Corriente max. recomendada: ~1.2A continuo
Protocolo:                  UART (1 pin de datos)
StealthChop:                Sí
StallGuard:                 Sí (detección sin fin de carrera)
Precio:                     ~3-5€/unidad
```

**Cuándo usarlo:** Motores NEMA 17 con corrientes bajas-medias (X, Y, extrusor).

**Ventaja clave:** Un solo pin UART para configuración y telemetría. El driver reporta temperatura, corriente y carga en tiempo real a Klipper.

**Limitación:** No aguanta 2A de forma continua. Si lo usas con un NEMA 23, el chip se calienta excesivamente y puede morir.

---

### TMC5160-T Pro (SPI)

```
Corriente max:   4.4A peak / 3A RMS
Protocolo:       SPI (4 cables: MISO, MOSI, SCK, CS)
StealthChop:     Sí
Tensión:         8–60V
Color:           Rojo (en nuestra placa)
Precio:          ~8-12€/unidad
```

**Cuándo usarlo:** Motores NEMA 23 que necesitan 2A o más.

**Ventaja clave:** Puede manejar corrientes altas sin calentarse. Los TMC5160 en nuestra placa corren a **2A run / 1A hold** para los NEMA 23 del eje Z — los TMC2209 no aguantarían esto.

**Configuración SPI compartida:** Todos los TMC5160 comparten los mismos pines MISO/MOSI/SCK, pero cada uno tiene su propio `cs_pin` (Chip Select):
```ini
[tmc5160 stepper_z]
cs_pin: PD11    # MOTOR 1
spi_software_miso_pin: PA6
spi_software_mosi_pin: PA7
spi_software_sclk_pin: PA5

[tmc5160 stepper_z1]
cs_pin: PE4     # MOTOR 5
# mismos pines SPI
```

---

## NEMA 17 vs NEMA 23 — ¿Por qué usamos NEMA 23 en Z?

### NEMA 17 (ejes X, Y, extrusor)

```
Frame size: 42 × 42 mm
Par típico: 40–60 N·cm
Corriente:  0.4–1.7A
Peso:       ~250-350g
```

Para X e Y: el carro solo lleva el cabezal de impresión (ligero), así que NEMA 17 es más que suficiente.

### NEMA 23 (eje Z)

```
Frame size: 57 × 57 mm
Par típico: 100–200 N·cm
Corriente:  2–4A
Peso:       ~600-800g
```

**¿Por qué NEMA 23 en Z?**  
En esta impresora **la cama no se mueve** — el eje Z levanta el pórtico completo (eje X + carro + cabezal extrusor), que pesa varios kilos. El eje Z tiene que:
1. Levantar ese peso contra la gravedad en cada cambio de capa
2. Mantener el pórtico estable durante la impresión
3. Hacer micro-ajustes precisos e independientes para el `Z_TILT_ADJUST`

Un NEMA 17 se quedaría corto de torque y perdería pasos al subir.

---

## Eje Y — Doble motor en paralelo con 1 solo driver

### Por qué 2 motores en Y

Con **1000mm de recorrido en Y**, un único motor en un extremo generaría un par de fuerzas que desplazaría lateralmente el carro durante el movimiento. Con un motor en cada lado del eje, el empuje es simétrico: el carro se mantiene centrado y alineado sin desviaciones laterales ni vibraciones desiguales.

### Por qué 1 solo driver para 2 motores

Los dos motores van conectados **en paralelo** al mismo slot (MOTOR 2_1 y MOTOR 2_2 físicamente conectados al driver del 2_1). Ventajas:
- Ahorramos un slot de driver
- Los dos motores se mueven **exactamente igual** (mismo driver = mismas señales)
- No hay riesgo de desincronización

**Inconveniente:** La corriente se divide entre los dos motores. Con `run_current: 1.0A`, cada motor recibe 0.5A — suficiente para NEMA 17 en Y.

```ini
[stepper_y]
step_pin: PF11    # MOTOR 2_1 — driver único
# El segundo motor (MOTOR 2_2) se conecta en paralelo al mismo slot
# No tiene sección propia en printer.cfg
```

### ¿Por qué NO usar Z_TILT para Y?

Podríamos haber puesto 2 drivers independientes para Y (como hacemos en Z con Z_TILT), pero en Y no necesitamos corrección de inclinación — la correa ya asegura que ambos extremos estén sincronizados.

---

## Extrusor — LDO Smart Orbiter v3.0 con TMC2209

El extrusor es especial: queremos **máxima respuesta** en los cambios de velocidad (aceleración/deceleración rápida del filamento).

Por eso, el TMC2209 del extrusor tiene **StealthChop desactivado**:

```ini
[tmc2209 extruder]
stealthchop_threshold: 0   # 0 = StealthChop SIEMPRE desactivado
```

StealthChop hace el motor más silencioso pero menos reactivo. Para el extrusor preferimos precisión sobre silencio.

---

## Configuración de corrientes

La corriente correcta para cada driver se calcula así:

```
run_current = I_nominal_motor × 0.707
```

Por ejemplo, para el SO3 (corriente nominal del motor: 1A):
```
run_current = 1.0 × 0.707 ≈ 0.707A → ponemos 0.85A (ligeramente superior para SO3)
```

Para los NEMA 23 (corriente nominal: ~2.8A), ponemos 2.0A — limitado por el límite de la fuente de alimentación y el calor generado.

| Motor | Corriente nominal | run_current | hold_current |
|---|---|---|---|
| X (NEMA17) | ~1.5A | 0.6A | 0.3A |
| Y (NEMA17 ×2 paralelo) | ~1.5A | 1.0A (total) | 0.5A |
| Z (NEMA23) | ~2.8A | 2.0A | 1.0A |
| Extrusor (LDO) | ~1.0A | 0.85A | 0.1A |

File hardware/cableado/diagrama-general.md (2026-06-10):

# Diagrama general de cableado

> Vista simplificada de todas las conexiones eléctricas del sistema.

---

## Diagrama de bloques

```
┌─────────────────────────────────────────────────────────────────────┐
│                    FUENTE DE ALIMENTACIÓN 24V                       │
└──────────┬───────────────────────┬──────────────────────────────────┘
           │                       │
    MOTOR-POWER + POWER         BED-POWER
           │                       │
           ▼                       ▼
┌──────────────────────────────────────────────────────────────────────┐
│                   BTT OCTOPUS PRO V1.1 (STM32H723)                  │
│                                                                      │
│  MOTOR0──TMC2209──► Motor X (NEMA17)                                │
│  MOTOR2_1 TMC2209──► Motor Y izq (NEMA17) ┐ En paralelo            │
│  MOTOR2_2─────────► Motor Y der (NEMA17)  ┘                        │
│  MOTOR1──TMC5160──► Motor Z izq (NEMA23)                            │
│  MOTOR5──TMC5160──► Motor Z der (NEMA23)  [MOTOR3 = DEFECTUOSO]    │
│  MOTOR4──TMC2209──► Extrusor SO3 (LDO)                             │
│                                                                      │
│  T1 (PF5)    ◄──── Endstop X                                       │
│  T2 (PF6)    ◄──── Endstop Y                                       │
│  T3 (PF7)    ◄──── Endstop Z máximo (seguridad)                    │
│  PB6 / PB7   ◄──► CR Touch (control + sensor)                      │
│                                                                      │
│  T0 (PF4)    ◄──── Termistor hotend (ATC Semitec 104NT-4)          │
│  BED (PF3)   ◄──── Termistor cama (pendiente instalar)             │
│  HE0 (PA3)   ────► Calentador hotend 24V 72W                       │
│  HE_BED(PA1) ────► Cama calefactada 24V                            │
│  FAN2 (PD12) ────► Ventilador heatsink SO3                         │
│  FAN3 (PD13) ────► Ventilador de capa (J53)                        │
│                                                                      │
│  PG11 ◄────────── Sensor filamento SO3                              │
│  PG10 ◄────────── Botón descarga SO3                               │
│                                                                      │
│  USB-C ◄─────────► BTT CB1 (ARM, Klipper host, Fluidd web UI)      │
└──────────────────────────────────────────────────────────────────────┘
```

---

## CR Touch — 5 cables (detalle)

```
CR Touch ALT04
  ┌─────────────┐
  │ Azul   PB7  │── Sensor (señal de toque) → ^ pullup
  │ Rojo   GND  │── Masa
  │ Amarillo PB6│── Control servo (deploy / retract)
  │ Negro  5V   │── Alimentación 5V
  │ Blanco GND  │── Masa
  └─────────────┘
```

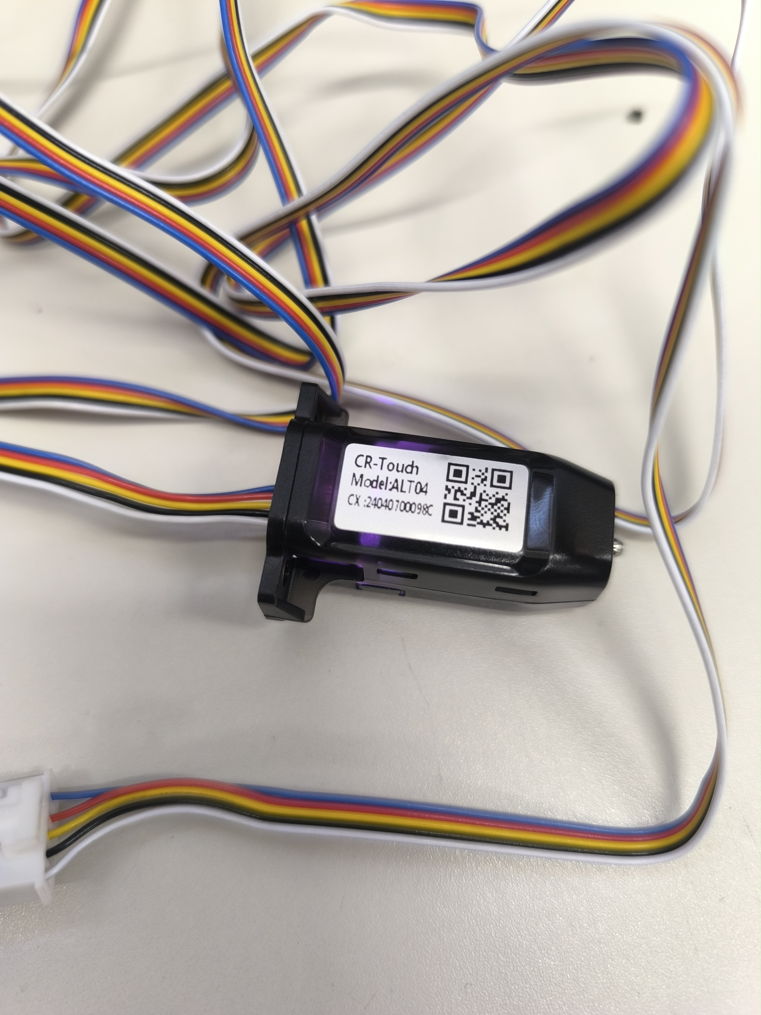
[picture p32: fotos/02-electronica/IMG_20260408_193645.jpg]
CR Touch cables

*CR Touch ALT04 con su cable de 5 colores.*

---

## TMC5160 — Bus SPI compartido

Los dos drivers TMC5160 (Z izq y Z der) comparten el mismo bus SPI pero cada uno tiene su propio **Chip Select**:

```
Bus SPI (compartido):
  PA6 ──── MISO  ──── TMC5160 Z izq ──── TMC5160 Z der
  PA7 ──── MOSI
  PA5 ──── SCLK

Chip Select (individual):
  PD11 ──── CS del TMC5160 Z izq (MOTOR 1)
  PE4  ──── CS del TMC5160 Z der (MOTOR 5)
```

---

## Jumpers de voltaje en la Octopus Pro

**Importante**: Los TMC5160 necesitan el jumper en posición `VFused` (tensión del motor), no en 5V.

```
Cada slot de driver tiene 3 jumpers de voltaje:
  [VFused] [VFused] [VFused]  ← posición correcta para TMC5160 y TMC2209
```

---

## Cable del hotend (etiquetado)

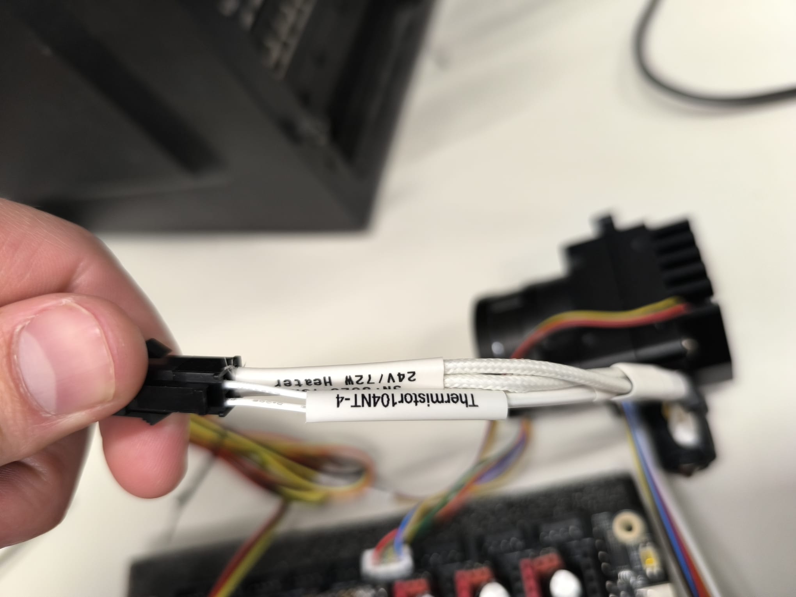
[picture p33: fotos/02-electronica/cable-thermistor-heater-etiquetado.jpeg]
Cable hotend etiquetado

*Cable del extrusor con etiquetas: "Thermistor104NT-4" y "24V/72W Heater".*

```
Conector hotend → Octopus Pro:
  Termistor (2 cables blancos) ──── T0 (PF4)
  Calentador (2 cables negros) ──── HE0 (PA3)
```

---

## Cables de motor (NEMA17 y NEMA23)

Los motores paso a paso tienen 4 cables que forman 2 bobinas:

```
Motor → Conector JST 4 pines en placa:
  A+  ──── pin 1
  A-  ──── pin 2
  B+  ──── pin 3
  B-  ──── pin 4

⚠ Si el motor vibra sin moverse: A+ y A- están intercambiados
⚠ Si gira al revés: cambiar ! en dir_pin (o intercambiar A+ con B+)
```

---

## Cables "EXTRUSOR" etiquetados en la máquina

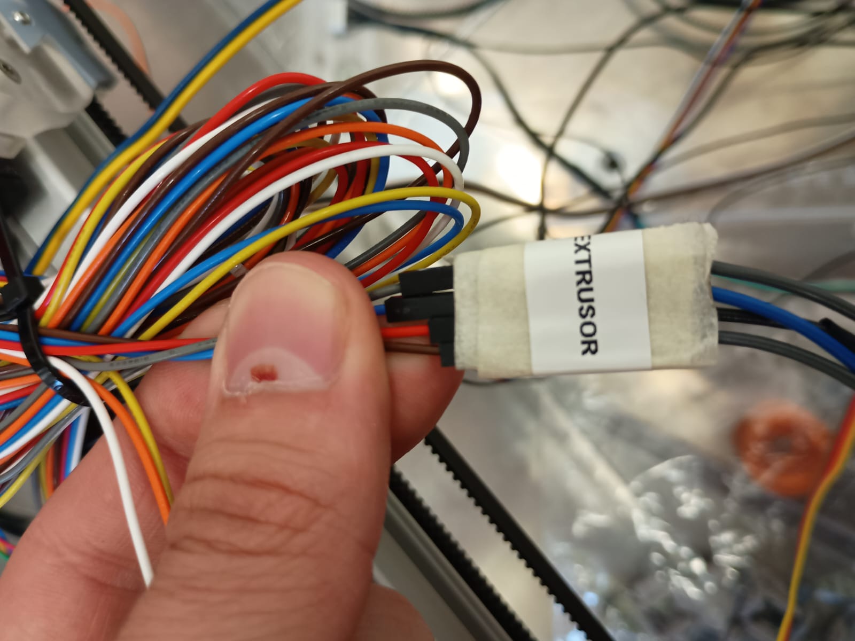
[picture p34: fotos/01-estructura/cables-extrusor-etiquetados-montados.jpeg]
Cables extrusor montados

*Mazo de cables del cabezal etiquetados como "EXTRUSOR" ya montados en la impresora.*

Los cables del cabezal incluyen: termistor, calentador, motor extrusor, ventilador, sensor filamento, botón descarga y CR Touch.

---

## Diagrama de alimentación

```
Fuente 24V
  ├── MOTOR-POWER ──── Todos los slots de driver (MOTOR 0-7)
  ├── POWER       ──── Lógica + ventiladores + hotend heater
  └── BED-POWER   ──── Cama calefactada (rail separado)
```

> **Por qué separar BED-POWER:** La cama consume mucha corriente (puede ser 10-20A). Si comparte rail con los motores, los picos de corriente pueden causar fallos de paso o ruido en las señales.

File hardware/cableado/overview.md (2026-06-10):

# Cableado — Vista general

> Mapa de conexiones de todos los sistemas a la BTT Octopus Pro V1.1.

---

## Diagrama de sistemas

```mermaid
graph TD
    PSU[Fuente de alimentación 24V] --> OCT[BTT Octopus Pro V1.1]
    CB1[BTT CB1 ARM] <-->|USB-C| OCT

    OCT -->|MOTOR 0 - UART| X[Motor X - NEMA17]
    OCT -->|MOTOR 2_1 - UART| Y1[Motor Y izq - NEMA17]
    OCT -->|MOTOR 2_2 paralelo| Y2[Motor Y der - NEMA17]
    OCT -->|MOTOR 1 - SPI| Z1[Motor Z izq - NEMA23]
    OCT -->|MOTOR 5 - SPI| Z2[Motor Z der - NEMA23]
    OCT -->|MOTOR 4 - UART| EXT[Extrusor SO3 - LDO]

    OCT -->|PF5 T1 endstop| ES_X[Endstop X]
    OCT -->|PF6 T2 endstop| ES_Y[Endstop Y]
    OCT -->|PF7 T3| ES_ZMAX[Endstop Z máximo]
    OCT -->|PB6 control / PB7 sensor| CRT[CR Touch ALT04]

    OCT -->|PF4 T0| THERM_E[Termistor extrusor]
    OCT -->|PF3 T1| THERM_B[Termistor cama pendiente]
    OCT -->|PA3 HE0| HEAT_E[Calentador hotend 24V 72W]
    OCT -->|PA1 HE_BED| HEAT_B[Calentador cama]

    OCT -->|PD12 FAN2| FAN_HS[Ventilador heatsink SO3]
    OCT -->|PG11 endstop| FIL[Sensor filamento SO3]
    OCT -->|PG10 gcode_button| BTN[Botón descarga SO3]
```

---

## Mapa de slots usados

| Slot físico | Componente | Driver | Pin step | Pin dir | Pin enable |
|---|---|---|---|---|---|
| MOTOR 0 | Motor X | TMC2209 | PF13 | PF12 | !PF14 |
| MOTOR 1 | Motor Z izq | TMC5160 | PG0 | PG1 | !PF15 |
| MOTOR 2_1 | Motor Y (×2 paralelo) | TMC2209 | PF11 | PG3 | !PG5 |
| MOTOR 2_2 | Motor Y derecho (paralelo) | — | — | — | — |
| MOTOR 3 | **DEFECTUOSO** — no usar | — | — | — | — |
| MOTOR 4 | Extrusor SO3 | TMC2209 | PF9 | PF10 | !PG2 |
| MOTOR 5 | Motor Z der | TMC5160 | PC13 | !PF0 | !PF1 |

> El `!` en dir_pin = inversión de dirección (el motor giraría al revés sin él).

---

## Pines de endstop

| Componente | Pin | Modo | Conector en placa |
|---|-----|---|---|
| Endstop X | PF5 | Digital, pullup invertido | T1 |
| Endstop Y | PF6 | Digital, pullup invertido | T2 |
| Endstop Z virtual | probe:z_virtual_endstop | CR Touch | (via bltouch) |
| Endstop Z máximo | PF7 | Digital, pullup | T3 |

---

## Pines de temperatura

| Componente | Pin | Tipo | Conector |
|---|-----|---|---|
| Termistor extrusor | PF4 | ATC Semitec 104NT-4-R025H42G | T0 (J45) |
| Termistor cama | PF3 | EPCOS 100K (placeholder) | BED (J44) |

---

## Pines de calefacción

| Componente | Pin | Especificación |
|---|-----|---|
| Hotend | PA3 | 24V, 72W cerámico |
| Cama | PA1 | 24V (potencia variable) |

---

## Pines de ventilador

| Ventilador | Pin | Tipo en Klipper |
|---|-----|---|
| Heatsink SO3 | PD12 (FAN2) | `[heater_fan]` — controlado por temp hotend |
| Ventilador de capa | PD13 (FAN3, J53) | `[fan]` — controlado por el slicer (M106/M107) |

---

## CR Touch — Pinout completo

| Cable | Color | Función | Pin Octopus |
|---|---|---|---|
| 1 | Azul | Sensor / señal touch | PB7 |
| 2 | Rojo | GND | GND |
| 3 | Amarillo | Control (servo) | PB6 |
| 4 | Negro | 5V | 5V |
| 5 | Blanco | GND | GND |

---

## Alimentación

La Octopus Pro tiene tres entradas de alimentación independientes:

```
MOTOR-POWER   → 24V — alimenta los drivers (1-8 todos)
POWER         → 24V — alimenta la lógica, ventiladores, hotend
BED-POWER     → 24V — alimenta exclusivamente la cama calefactada
BED-OUT       → salida hacia la cama
```

> Separar BED-POWER del resto es importante: la cama consume mucha corriente y puede causar ruido en la señal de los motores si comparte rail con ellos.

**Configuración actual:** las tres entradas están puenteadas para usar una sola fuente 24V.  
**Futuro:** separar BED-POWER para conectar un relé de alta potencia (4 camas 500×500mm en paralelo).

---

## Crimpado de cables

Todos los conectores JST del proyecto están crimpados a mano con la herramienta apropiada.

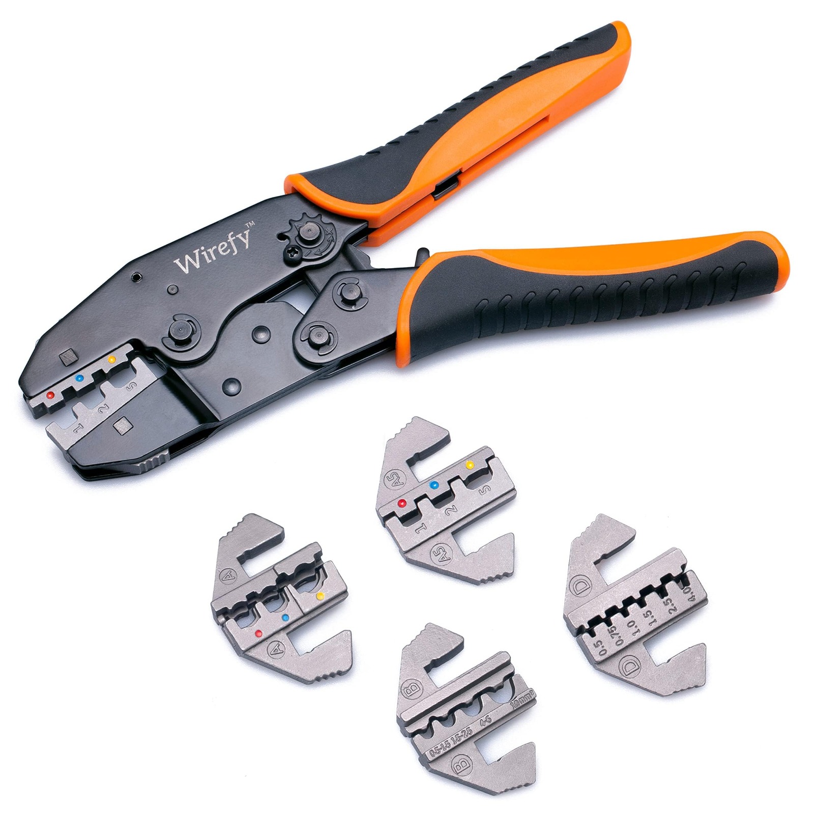
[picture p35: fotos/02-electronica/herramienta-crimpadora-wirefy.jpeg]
Herramienta crimpadora

*Herramienta crimpadora Wirefy con juego de matrices intercambiables. Cada matriz corresponde a un tamaño de terminal: 0.5mm², 1mm², 1.5mm², 2.5mm². Los cables se cortan a la longitud necesaria y se crimpa el terminal antes de insertar en la carcasa JST.*

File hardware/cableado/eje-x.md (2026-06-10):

# Cableado — Eje X

## Componentes

| Componente | Especificación |
|---|---|
| Motor | NEMA 17 |
| Driver | TMC2209 (UART) |
| Slot placa | MOTOR 0 |
| Endstop | Final de carrera mecánico |
| Transmisión | Correa GT2, polea 20 dientes |

## Configuración en printer.cfg

```ini
[stepper_x]
step_pin: PF13
dir_pin: PF12
enable_pin: !PF14
microsteps: 16
rotation_distance: 40      # polea 20T × 2mm paso GT2 = 40mm/vuelta
endstop_pin: ^!PF5         # T1 - pullup + lógica invertida
position_endstop: 0        # home en posición 0 (extremo izquierdo)
position_max: 1000         # recorrido máximo 1000mm
homing_speed: 50

[tmc2209 stepper_x]
uart_pin: PC4
run_current: 0.600
hold_current: 0.300
stealthchop_threshold: 999999   # StealthChop siempre activo
```

## Cálculo de rotation_distance

```
rotation_distance = dientes_polea × paso_correa
rotation_distance = 20 × 2mm = 40mm
```

Con `microsteps: 16` y un motor de 200 pasos/vuelta:
```
Resolución = 40mm / (200 × 16) = 0.0125mm = 12.5 micras por paso
```

## Cableado del motor

El motor NEMA 17 tiene 4 cables que forman 2 bobinas (A y B):

```
Motor NEMA17 → conector JST en MOTOR 0
  A+ →  pin 1
  A- →  pin 2
  B+ →  pin 3
  B- →  pin 4
```

> Si el motor vibra sin moverse, el orden A+/A- o B+/B- está invertido. Intercambiar los dos cables de una bobina.

## Cableado del endstop

```
Endstop X → T1 (PF5)
  Señal → PF5
  GND   → GND del conector
```

El `^!` en `endstop_pin: ^!PF5` activa el pullup interno y la lógica invertida del STM32.

## Diagrama simplificado

```
MOTOR 0 ─────────── NEMA17 eje X
    step: PF13
    dir:  PF12
    ena:  !PF14
    uart: PC4 (TMC2209)

T1 (PF5) ────────── Endstop X
```

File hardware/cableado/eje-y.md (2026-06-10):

# Cableado — Eje Y (Dual motor en paralelo)

## Componentes

| Componente | Especificación |
|---|---|
| Motores | 2× NEMA 17 (en paralelo) |
| Driver | 1× TMC2209 (UART) — comparte los 2 motores |
| Slot placa | MOTOR 2_1 (driver) + MOTOR 2_2 (sin driver, paralelo físico) |
| Endstop | Final de carrera mecánico |
| Transmisión | Correa GT2, polea 20 dientes |

---

## Configuración en printer.cfg

```ini
[stepper_y]
step_pin: PF11             # MOTOR 2_1 — único driver
dir_pin: PG3
enable_pin: !PG5
microsteps: 16
rotation_distance: 40      # polea 20T × 2mm paso GT2 = 40mm/vuelta
endstop_pin: ^!PF6         # T2 - pullup + lógica invertida
position_endstop: 0
position_max: 1000
homing_speed: 50

[tmc2209 stepper_y]
uart_pin: PC6              # UART del slot MOTOR 2_1
run_current: 1.000         # 1A total ÷ 2 motores en paralelo = 0.5A cada uno
hold_current: 0.500
stealthchop_threshold: 999999
```

> El segundo motor (slot 2_2) se conecta físicamente en paralelo al primero. **No tiene sección propia en printer.cfg** — un solo driver los controla a ambos.

---

## Diagrama de cableado en paralelo

```
Driver TMC2209 (MOTOR 2_1)
    └── Motor Y izquierdo (MOTOR 2_1)
         ├── A+ ──── A+ motor izquierdo
         ├── A- ──── A- motor izquierdo
         ├── B+ ──── B+ motor izquierdo
         └── B- ──── B- motor izquierdo

    └── Motor Y derecho (MOTOR 2_2 físicamente, paralelo eléctrico)
         ├── A+ ──── A+ motor derecho
         ├── A- ──── A- motor derecho  
         ├── B+ ──── B+ motor derecho
         └── B- ──── B- motor derecho
```

Los dos conectores de salida de la Octopus Pro para MOTOR 2_1 y MOTOR 2_2 están eléctricamente conectados — ambos llevan las mismas señales step/dir/enable del mismo driver.

---

## Historia: de 1 motor a 2 en paralelo

**Configuración inicial:** 1 solo motor Y en MOTOR 2_1.

**Problema:** Con 1000mm de recorrido, un solo motor en un extremo causaría:
- Asimetría de fuerzas → el eje se tuerce levemente
- Pérdida de pasos en aceleraciones altas

**Solución:** Añadir un segundo motor NEMA 17 en paralelo en el otro extremo del eje.

Ver: [Problema — Eje Y dual](../../problemas/eje-y-dual.md)

---

## Endstop Y

```
Endstop Y → T2 (PF6)
  Señal → PF6
  GND   → GND
```

El endstop se activa cuando el carro Y llega al extremo trasero (posición 0). El home mueve el carro hacia atrás hasta activar el endstop, luego retrocede a position_endstop.

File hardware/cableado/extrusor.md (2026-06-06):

# Cableado — LDO Smart Orbiter v3.0

> El extrusor es el componente más complejo del cabezal: motor, hotend, termistor, calentador, ventilador, sensor de filamento y botón de descarga.

---

## Cables del cabezal instalados en la impresora

Cable EXTRUSOR etiquetado
*Mazo de cables del cabezal con etiqueta "EXTRUSOR" ya instalado en la impresora. El mazo incluye: motor, termistor, calentador, ventilador, sensor de filamento, botón y CR Touch.*

Cable hotend etiquetado detalle
*Detalle del extremo del conector: etiquetas "Thermistor104NT-4" y "24V/72W Heater" para identificar cada cable sin errores.*

---

## Componentes del cabezal

| Componente | Especificación |
|---|---|
| Extrusor | LDO Smart Orbiter v3.0 (direct drive, reducción 7.5:1) |
| Motor | LDO-36STH20-1004AHG (compacto, 1A nominal) |
| Driver | TMC2209 (UART), slot MOTOR 4 |
| Termistor | ATC Semitec 104NT-4-R025H42G |
| Calentador | 24V, 72W cerámico |
| Ventilador heatsink | Frameless 24V (integrado en SO3) |
| Sensor filamento | Integrado en SO3 (switch) |
| Botón descarga | Integrado en SO3 |

---

## Motor y driver

```ini
[extruder]
step_pin: PF9
dir_pin: PF10
enable_pin: !PG2
microsteps: 16
full_steps_per_rotation: 200
rotation_distance: 4.637   # calibrado (oficial SO3: 4.69)
nozzle_diameter: 0.400
filament_diameter: 1.750
max_extrude_only_distance: 500
max_extrude_only_velocity: 120

[tmc2209 extruder]
uart_pin: PF2
run_current: 0.850
hold_current: 0.100
stealthchop_threshold: 0   # StealthChop DESACTIVADO — máxima respuesta
```

### Por qué StealthChop desactivado en el extrusor

StealthChop hace el motor silencioso pero introduce latencia en los cambios de velocidad. Para el extrusor necesitamos **máxima respuesta** en las aceleraciones y deceleraciones de filamento. El ruido extra del extrusor es aceptable.

### Calibración de rotation_distance

El SO3 tiene una relación de reducción de 7.5:1. El valor oficial es `4.69`, pero fue necesario calibrarlo:

```bash
# Procedimiento de calibración:
# 1. Marcar el filamento a 100mm de la entrada
# 2. Enviar comando de extrusión: G1 E100 F100
# 3. Medir cuánto filamento entró realmente (por ej: 98.7mm)
# 4. rotation_distance_nuevo = rotation_distance_actual × (medido / pedido)
# 4.69 × (98.7 / 100) = 4.637
```

---

## Hotend

```ini
heater_pin: PA3            # HE0 — calentador cerámico 24V 72W
sensor_type: ATC Semitec 104NT-4-R025H42G
sensor_pin: PF4            # T0 — termistor
min_temp: 0
max_temp: 300
min_extrude_temp: 170      # protección: no extruye frío

# PID calibrado (resultado de PID_CALIBRATE HEATER=extruder TARGET=220)
control = pid
pid_kp = 22.602
pid_ki = 1.408
pid_kd = 90.690
```

El bloque PID quedó guardado automáticamente en `#*# SAVE_CONFIG` tras ejecutar:
```
PID_CALIBRATE HEATER=extruder TARGET=220
SAVE_CONFIG
```

---

## Ventilador heatsink

El SO3 tiene un ventilador frameless integrado. **Solo tiene 2 pines** (VCC y GND), sin señal PWM.

```ini
[heater_fan hotend_fan]
pin: PD12              # FAN2 de la Octopus Pro
heater: extruder
heater_temp: 50.0      # se activa cuando hotend > 50°C
fan_speed: 1.0         # siempre a máxima velocidad cuando activo
```

**Cableado del ventilador frameless:**
```
Ventilador SO3 (2 cables):
  Rojo  → VCC FAN2 en Octopus
  Negro → GND FAN2 en Octopus
  (El tercer cable amarillo de señal PWM no se conecta)
```

> Los conectores FAN de la Octopus Pro tienen 3 pines (VCC, GND, señal). Para ventiladores de 2 hilos, solo conectar VCC y GND.

---

## Sensor de filamento

```ini
[filament_switch_sensor sensor_filamento]
switch_pin: ^PG11
pause_on_runout: True
runout_gcode:
  M118 Filamento agotado - pausando impresion
```

Cuando el filamento se agota, el sensor abre el circuito → Klipper pausa la impresión automáticamente.

## Botón de descarga

```ini
[gcode_button boton_descarga]
pin: ^!PG10            # ^! = pullup + lógica invertida (normalmente cerrado)
press_gcode:           # (vacío)
release_gcode:
  M118 Boton descarga pulsado
  filament_unload_init
```

Al soltar el botón físico (no al pulsar), ejecuta la macro de descarga:

```ini
[gcode_macro filament_unload_init]
gcode:
  {% if printer.print_stats.state != "printing" %}
    M109 S185          # calentar a 185°C
    G92 E0
    G1 E-5 F3000       # retracción rápida 5mm
    G1 E-25 F300       # retracción lenta 25mm
    M104 S0            # apagar calefactor
  {% else %}
    M118 No se puede descargar mientras se imprime!
  {% endif %}
```

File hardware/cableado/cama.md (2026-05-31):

# Cableado — Cama calefactada

## Estado actual

> ⚠️ **La cama calefactada NO está instalada todavía.**  
> No existe una cama de 1000×1000mm estándar — la solución prevista es montar **4 camas calefactadas de 500×500mm** en paralelo. La configuración actual es un parche temporal para poder arrancar Klipper sin cama real.

---

## Componentes

| Componente | Estado | Pin |
|---|---|-----|
| Calentador cama | ❌ Pendiente instalar | PA1 (HE_BED) |
| Termistor temperatura | ❌ Pendiente instalar | PF3 (T1) |

---

## Configuración actual (parche temporal)

```ini
[heater_bed]
heater_pin: PA1
sensor_type: EPCOS 100K B57560G104F   # placeholder — no hay sensor real
sensor_pin: PF3
control: watermark
min_temp: -110    # muy bajo para que no falle sin sensor
max_temp: 130
```

`min_temp: -110` evita que Klipper bloquee el inicio cuando el pin PF3 lee un valor fuera de rango (porque no hay termistor conectado).

---

## Instalación pendiente del termistor

Para completar la cama calefactada:

1. **Comprar:** 4 camas calefactadas estándar de **500×500mm** y montarlas cubriendo el área 1000×1000mm
2. **Comprar:** Termistor NTC 100K tipo EPCOS B57560G104F (o genérico 100K B3950) — uno por zona o uno central
3. **Montar:** Pegar termistor en la parte inferior de la placa calefactora con cinta de kapton
4. **Conectar:** Al pin PF3 (conector T1 de la Octopus Pro)
5. **Actualizar config:**

```ini
[heater_bed]
heater_pin: PA1
sensor_type: EPCOS 100K B57560G104F
sensor_pin: PF3
control: pid              # cambiar de watermark a pid
min_temp: 0               # restaurar a valor normal
max_temp: 130
```

6. **Calibrar PID de cama:**
```
PID_CALIBRATE HEATER=heater_bed TARGET=60
SAVE_CONFIG
```

---

## Cableado del calentador

La cama de 1m² necesita un calentador de alta potencia (típicamente 1000-2000W). Los cables van directamente al conector BED-OUT de la Octopus Pro, que alimenta el MOSFET que controla la cama.

```
Cama calefactora:
  Cable 1 (positivo) → BED-OUT +
  Cable 2 (negativo) → BED-OUT -

Alimentación BED-POWER separada:
  BED-POWER + → fuente 24V (rail dedicado)
  BED-POWER - → GND fuente
```

> La Octopus Pro tiene entradas de alimentación **separadas** para la cama (BED-POWER) y para el resto de la placa (POWER). Es importante mantenerlas separadas para evitar ruido en las señales de los motores.

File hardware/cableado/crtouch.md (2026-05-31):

# Cableado — CR Touch (Sonda Z virtual)

> El CR Touch reemplaza el endstop físico de Z y permite nivelación automática de la cama.

---

## Modelo

**Creality CR Touch — ALT04** (CX:24040700098C)

CR Touch ALT04
*CR Touch modelo ALT04 con su cable de 5 colores. El lado izquierdo es el conector de la placa (JST), el derecho el del sensor.*

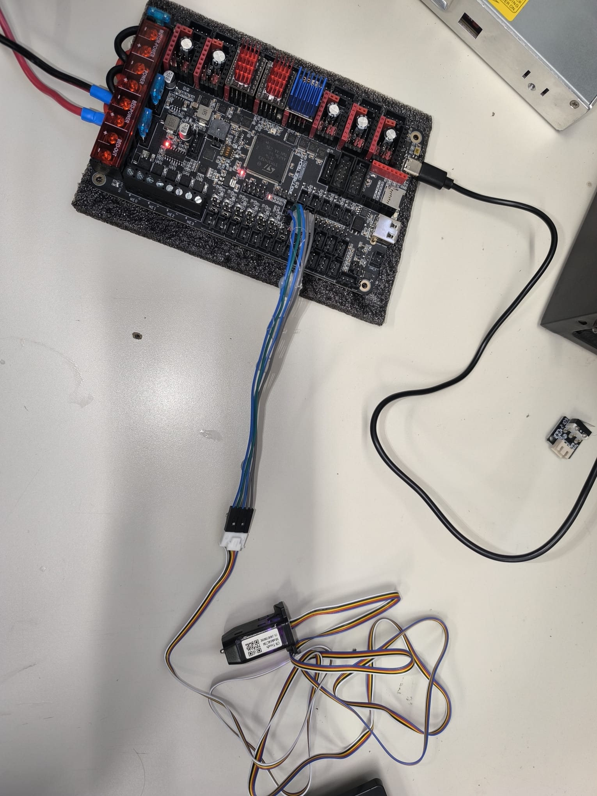
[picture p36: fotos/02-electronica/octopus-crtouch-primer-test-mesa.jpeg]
CR Touch conectado a placa

*CR Touch conectado a la Octopus Pro para el primer test. Se puede ver el cable de 5 hilos conectado a los pines PB6 (amarillo) y PB7 (azul).*

Conexión CR Touch
*Proceso de conexión: insertando el conector JST del CR Touch en los pines correctos de la Octopus Pro.*

---

## Pinout — Los 5 cables

| Cable | Color | Función | Pin Octopus Pro |
|---|---|---|---|
| 1 | Azul | Señal de sensor (toque) | **PB7** |
| 2 | Rojo | GND | GND |
| 3 | Amarillo | Control del servo (deploy/retract) | **PB6** |
| 4 | Negro | 5V alimentación | 5V |
| 5 | Blanco | GND | GND |

> Los colores pueden variar ligeramente entre fabricantes. Verificar con el manual incluido en la caja.

---

## Configuración en printer.cfg

```ini
[bltouch]
sensor_pin: ^PB7           # ^ = pullup. Señal de detección de toque
control_pin: PB6           # Control del servo
pin_up_touch_mode_reports_triggered: False
x_offset: 0               # Offset respecto a la boquilla (calibrar físicamente)
y_offset: 0               # Offset Y (calibrar físicamente)
z_offset: 0               # Calibrar con PROBE_CALIBRATE
speed: 5.0                # Velocidad de sondeo (lenta para precisión)
lift_speed: 10.0
samples: 2                # 2 muestras por punto (promedio)
sample_retract_dist: 5.0
```

### Homing seguro con CR Touch

```ini
[safe_z_home]
home_xy_position: 500, 500  # Centro de la cama 1000×1000
speed: 100
z_hop: 10                   # Sube 10mm antes de moverse (evita roces)
z_hop_speed: 10
```

El homing en Z funciona así:
1. Hace home en X e Y primero
2. Se mueve al centro de la cama (500, 500)
3. Baja lentamente hasta que el CR Touch detecta la cama
4. Esa posición es el "cero" de Z

---

## Bed Mesh — Mapa de nivelación 5×5

```ini
[bed_mesh]
speed: 100
horizontal_move_z: 5
mesh_min: 30, 30          # Esquina mínima del mapa
mesh_max: 970, 970        # Esquina máxima (margen respecto a 1000)
probe_count: 5, 5         # 5×5 = 25 puntos de sondeo
mesh_pps: 2, 2            # Interpolación entre puntos
algorithm: bicubic        # Algoritmo para superficies complejas
```

El mapa de 25 puntos compensa irregularidades de la cama. Klipper ajusta la altura Z en tiempo real durante la impresión para que la primera capa quede uniforme en toda la superficie de 1m².

---

## Calibración del z_offset

Procedimiento inicial:

```
# 1. Calentar a temperatura de impresión
M104 S210
M190 S60

# 2. Hacer home completo
G28

# 3. Iniciar calibración
PROBE_CALIBRATE

# 4. Bajar manualmente con papel (método del papel)
TESTZ Z=-0.1   # bajar 0.1mm
TESTZ Z=+0.05  # subir 0.05mm
# repetir hasta que el papel tenga resistencia mínima

# 5. Guardar
ACCEPT
SAVE_CONFIG
```

El valor se guarda automáticamente en el bloque `#*# SAVE_CONFIG` del `printer.cfg`.

---

## Por qué CR Touch en lugar de endstop mecánico en Z

Con una cama de 1m², es imposible nivelarla manualmente con suficiente precisión. El CR Touch permite:

1. **Nivelación automática** (`Z_TILT_ADJUST`) — iguala los dos motores Z
2. **Mapa de cama** (`BED_MESH_CALIBRATE`) — compensa ondulaciones de la superficie
3. **Reproducibilidad** — cada impresión empieza exactamente a la misma altura

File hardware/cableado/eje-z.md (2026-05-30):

# Cableado — Eje Z (Dual independiente)

> El eje Z es el más complejo del proyecto: dos motores NEMA 23 independientes con drivers TMC5160 de alta potencia, configurados para el `Z_TILT_ADJUST` de Klipper.

---

## Componentes

| Componente | Especificación |
|---|---|
| Motores | 2× NEMA 23 |
| Drivers | 2× TMC5160-T Pro (SPI) |
| Slot Z izquierdo | MOTOR 1 |
| Slot Z derecho | MOTOR 5 (MOTOR 3 defectuoso) |
| Transmisión | Husillo métrico 12, paso 2mm, 4 entradas |
| Endstop Z | CR Touch (virtual) + endstop mecánico de seguridad en tope |

---

## Configuración en printer.cfg

```ini
# Z IZQUIERDO — Motor principal
[stepper_z]
step_pin: PG0
dir_pin: PG1
enable_pin: !PF15
microsteps: 16
rotation_distance: 8       # 2mm paso × 4 entradas = 8mm/vuelta
endstop_pin: probe:z_virtual_endstop  # CR Touch como endstop
position_min: -2           # permite bajar 2mm bajo 0 para calibrar offset
position_max: 1000
homing_speed: 10

[tmc5160 stepper_z]
cs_pin: PD11               # Chip Select SPI — MOTOR 1
spi_software_miso_pin: PA6
spi_software_mosi_pin: PA7
spi_software_sclk_pin: PA5
run_current: 2.000         # NEMA23 necesita 2A
hold_current: 1.000
stealthchop_threshold: 999999
driver_TOFF: 3
driver_HSTRT: 4
driver_HEND: 3

# Z DERECHO — Motor esclavo
[stepper_z1]
step_pin: PC13             # MOTOR 5 (MOTOR 3 estaba defectuoso)
dir_pin: !PF0              # ! invertido — gira en la misma dirección que Z
enable_pin: !PF1
microsteps: 16
rotation_distance: 8

[tmc5160 stepper_z1]
cs_pin: PE4                # Chip Select SPI — MOTOR 5
spi_software_miso_pin: PA6
spi_software_mosi_pin: PA7
spi_software_sclk_pin: PA5
run_current: 2.000
hold_current: 1.000
stealthchop_threshold: 999999
driver_TOFF: 3
driver_HSTRT: 4
driver_HEND: 3
```

---

## Por qué `dir_pin: !PF0` en Z derecho

Los dos motores Z están montados en lados opuestos de la impresora. Si los dos giraran en la misma dirección absoluta, uno bajaría la cama y el otro la subiría — la cama se torcería.

Al añadir `!` (inversión) al `dir_pin` del Z derecho, un motor gira en sentido horario y el otro en antihorario — pero **ambos elevan o bajan la cama en la misma dirección**.

Esto se descubrió durante las pruebas:
> «Vale funciona bb, voy a girar el signo de exclamación porque uno gira al revés bb» — conversación

---

## SPI compartido entre los dos TMC5160

Los dos drivers TMC5160 comparten los pines de bus SPI (MISO, MOSI, SCLK) pero cada uno tiene su propio `cs_pin`:

```
SPI bus:
  MISO → PA6  (todos los TMC5160 conectados aquí)
  MOSI → PA7
  SCLK → PA5

Chip Select individual:
  Z izq (MOTOR 1) → PD11
  Z der (MOTOR 5) → PE4
```

El Chip Select determina cuál driver está activo en cada momento — los demás ignoran los datos del bus.

---

## Z_TILT_ADJUST — Para qué sirve

Con dos motores Z independientes, Klipper puede **corregir automáticamente** si la cama no está perfectamente nivelada de lado a lado.

```ini
[z_tilt]
z_positions:
    -50, 150    # posición física del husillo izquierdo (X, Y)
    350, 150    # posición física del husillo derecho
points:
    30, 150     # donde sondea el CR Touch para el lado izquierdo
    270, 150    # donde sondea para el lado derecho
speed: 50
horizontal_move_z: 5
```

Al ejecutar `Z_TILT_ADJUST`, Klipper:
1. Sondea el punto izquierdo con el CR Touch
2. Sondea el punto derecho
3. Calcula la diferencia
4. Mueve independientemente cada motor para igualar las alturas

---

## Endstop de seguridad Z máximo

```ini
[gcode_button endstop_z_max]
pin: ^PF7    # T3 — conector de temperatura reconvertido en entrada digital
press_gcode:
  M118 EMERGENCIA - Endstop Z maximo activado
  M112         # Parada de emergencia
```

Instalado en el tope físico superior de las guías Z. Si el software falla y el eje sube más de lo debido, el final de carrera mecánico detiene todo con `M112`.

---

## Cálculo de rotation_distance

```
Husillo T12, 4 entradas, 2mm de paso:
rotation_distance = 2mm × 4 = 8mm/vuelta

Con microsteps: 16 y 200 pasos/vuelta:
Resolución = 8mm / (200 × 16) = 0.0025mm = 2.5 micras
```

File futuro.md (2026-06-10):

# Proyectos a futuro

> Ideas y mejoras planificadas para continuar el desarrollo de la máquina.  
> Algunas son sencillas de implementar; otras son proyectos completos en sí mismos.

---

## Mejoras mecánicas

### 4 cabezales de impresión con cambio de color
Implementar un sistema de múltiples extrusores (4 cabezales) para impresión multicolor o multi-material en una sola pieza. Requiere modificaciones en el firmware (Klipper admite multi-extrusor nativo) y el diseño de un cabezal intercambiable o de tipo "herramienta".

### 4 husillos Z (de 2 a 4)
Añadir dos husillos adicionales en el eje Z para mejorar la rigidez del sistema en una máquina de este tamaño. Con 4 puntos de apoyo se reduce la deflexión y se puede usar `Z_TILT_ADJUST` con más puntos de sondeo.

### Sistema de cadenas portacables
Sustituir los cables libres actuales por cadenas portacables (cable chains) en los ejes X e Y. Mejora la durabilidad del cableado y da un aspecto más profesional.

### Guías lineales con lubricación automática
Instalar un sistema automático de engrase de las guías MGN15R. Existen dispositivos comerciales con tubos y depósito que aplican aceite periódicamente. Aumenta la vida útil de las guías y reduce el mantenimiento manual.

---

## Mejoras de materiales

### Placa PEI en vez de cristal
Sustituir la superficie de impresión de cristal por una placa PEI magnética. El PEI ofrece mejor adherencia para PETG, ABS y ASA, y permite quitar las piezas con un simple flexado de la lámina.

### Enclosure para ABS/ASA/PP
Para poder imprimir con ABS, ASA o polipropileno de forma consistente, la máquina necesita una carcasa cerrada que mantenga la temperatura ambiente elevada y evite las corrientes de aire. Los paneles de policarbonato corrugado con imanes de neodimio ya están planificados (ver [piezas impresas](hardware/piezas-impresas.md)).

### Extrusor de pellets
Diseñar o adaptar un extrusor que funcione directamente con pellets de plástico en lugar de filamento bobinado. Reduce el coste del material y abre la posibilidad de usar plástico reciclado.

### Boquilla 1.5 mm para impresión rápida
Para piezas grandes donde el detalle no es crítico, una boquilla de 1.5 mm acelera enormemente los tiempos de impresión. Actualmente la máquina tiene boquilla de 0.4 mm.

---

## Mejoras electrónicas y de control

### Encoders en los motores
Añadir encoders a los motores paso a paso para pasar a control en bucle cerrado. Elimina la pérdida de pasos y permite recuperar la posición si hay un obstáculo. Especialmente relevante en una máquina tan grande donde los errores acumulados son mayores.

### Sistema de recuperación de corte de luz
Implementar y probar la macro de power-loss recovery de Klipper. Cuando se va la luz, la posición se guarda en la SD; al volver la corriente, la impresión puede continuar desde donde se quedó.

> **Nota técnica**: el eje Z no cae cuando se corta la corriente porque los husillos trapezoidales son auto-frenantes por fricción. Sin embargo, con piezas muy pesadas sobre el cabezal podría bajar ligeramente.

### LEDs de estado de la máquina
- 🟢 **Verde**: todo OK, imprimiendo normalmente
- 🔴 **Rojo fijo**: error crítico (temperatura, endstop)
- 🟡 **Amarillo intermitente**: aviso (filamento agotado, temperatura fuera de rango)

Implementable con una tira LED WS2812B controlada desde Klipper con `[neopixel]`.

### Más setas de emergencia
Añadir pulsadores de parada de emergencia adicionales en diferentes puntos de la máquina (actualmente solo hay uno). Para una máquina de 1m³ operada en un taller escolar, es importante poder detener la máquina desde cualquier posición.

### Magnetotérmico (protección de sobrecarga)
Instalar un interruptor magnetotérmico en la línea de alimentación de la máquina. Protege contra sobrecargas de corriente y cortocircuitos, especialmente importante cuando se instale la cama calefactada de alta potencia (4 × 500×500mm en paralelo).

### Ventiladores en la caja de electrónica
Añadir ventiladores de extracción en el panel verde donde están la Octopus Pro y el CB1. Con la cama calefactada en funcionamiento y todos los drivers cargados, la temperatura dentro del panel puede subir considerablemente.

---

## Mejoras de software y documentación

### Certificado CE
Para que la máquina pueda ser usada oficialmente en cualquier centro educativo o cedida a otros institutos, necesitaría obtener el marcado CE que acredita el cumplimiento de las directivas europeas de seguridad eléctrica y electromagnética.

### Versiones del repositorio en catalán e inglés
Traducir toda la documentación al catalán (para uso local) y al inglés (para que otros proyectos internacionales puedan replicar la máquina).

### Render 3D explodido de la máquina
Crear un render con vista explosionada de todos los componentes para que sea fácil entender el ensamblaje sin tener la máquina delante. Pendiente cuando se suban los archivos STEP del marco.

---

## Pendientes inmediatos

- [ ] Instalar 4 × camas calefactadas 500×500mm en paralelo
- [ ] Subir archivos STL y STEP de piezas impresas
- [ ] Subir planos del marco en PDF
- [ ] Calibración final: PID cama, Z offset definitivo con `PROBE_CALIBRATE`
- [ ] Probar y validar macro de power-loss recovery

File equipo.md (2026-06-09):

# El equipo

<p align="center">
  Institut Jaume Huguet — Antiga Escola del Treball, Valls
</p>

> **Cicle Formatiu de Fabricació Additiva (CEFP) — Curso 2025-2026**  
> Proyecto realizado en el **Institut Jaume Huguet — Antiga Escola del Treball**, Valls.  
> Centro con más de 100 años de historia formando a profesionales técnicos en el Camp de Tarragona.  
> 🌐 [institutjaumehuguet.cat](https://institutjaumehuguet.cat)

---

## Agradecimientos

Un agradecimiento especial al **director del instituto** por confiar en el proyecto, aportar el presupuesto necesario para los componentes y ceder el espacio del taller para la construcción. Sin su apoyo este proyecto no habría sido posible.

---

## Profesores

| Nombre | Rol |
|---|-----|
| **Fèlix Garcia Garcia** | Tutor técnico del proyecto. Supervisión general, revisión de documentación y validación técnica. |
| **Héctor Zazo Jiménez** | Apoyo en electrónica, cableado eléctrico e informática. Supervisión de las conexiones eléctricas y los sistemas informáticos del proyecto. |
| **Raquel Muñoz** | Seguimiento pedagógico del proyecto. |

---

## Alumnos

| Nombre | Rol principal |
|---|---|
| **Simeon Crasiuc** | Firmware (Klipper / printer.cfg), electrónica, cableado, documentación GitHub. |
| **Pau Arias March** | Diseño y fabricación de piezas impresas en 3D, montaje mecánico. |
| **Daniel Roselló Díaz** | Montaje estructura, cableado, fotos del proceso. |
| **Sergio Tenorio Martínez** | Diseño CAD del marco, planos estructurales item, archivos 3D (STL/STEP pendientes de subir). |

---

## El instituto

El **Institut Jaume Huguet** es un centro de formación profesional de Valls (Tarragona) con más de 100 años de historia. Ofrece ciclos formativos de grado medio y superior en áreas como electricidad, electrónica, mecánica, informática y administración.

Este proyecto de impresora 3D de gran formato forma parte de un trabajo de clase con el objetivo de que la máquina **se quede en el instituto** para que pueda ser usada por futuros alumnos, replicada por otros centros, y sirva como plataforma de aprendizaje en fabricación digital avanzada.

---

## Versiones del repositorio

Este repositorio está disponible en tres idiomas:

| Idioma | Repositorio |
|---|---|
| 🇪🇸 Español | **este repositorio** |
| 🏴󠁥󠁳󠁣󠁴󠁿 Català | [impresora-3d-1000x1000-ca](https://github.com/xXSimon91Xx/impresora-3d-1000x1000-ca) |
| 🇬🇧 English | [impresora-3d-1000x1000-en](https://github.com/xXSimon91Xx/impresora-3d-1000x1000-en) |

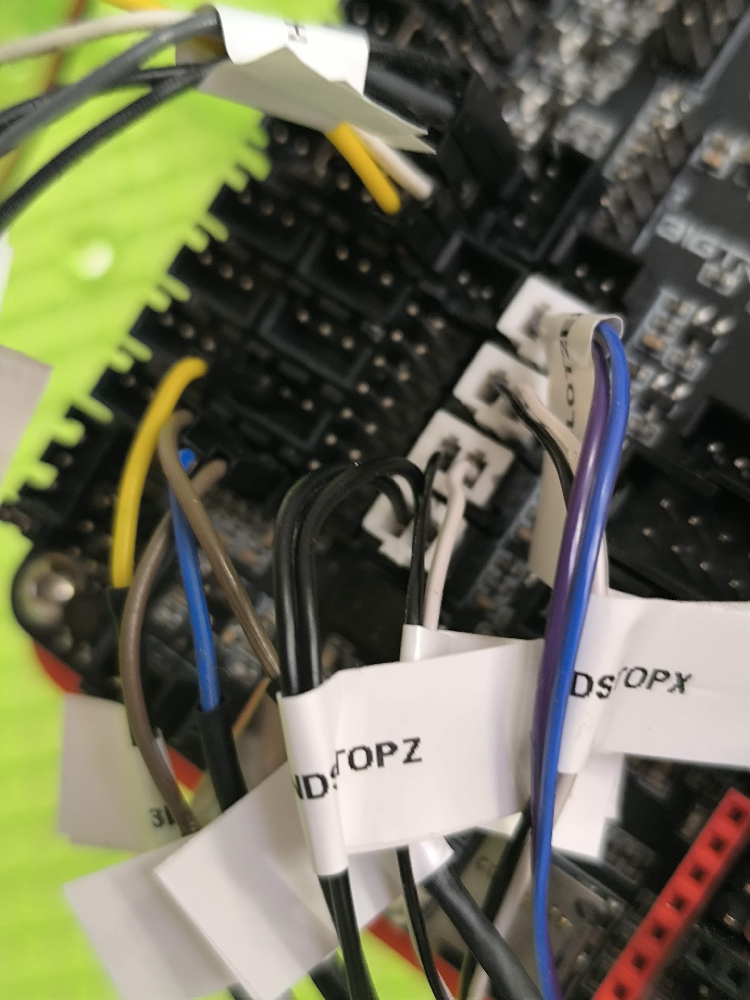
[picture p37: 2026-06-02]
fotos/02-electronica/cables-ndstopz-ndstopx-etiquetados.jpg

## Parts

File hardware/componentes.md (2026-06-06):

# Lista de componentes (BOM)

> Por qué elegimos cada pieza — el razonamiento detrás de cada elección.

---

## Electrónica principal

### BTT Octopus Pro V1.1 (STM32H723)

| Campo | Valor |
|---|---|
| **MCU** | STM32H723ZET6 (ARM Cortex-M7, 550 MHz) |
| **Slots de driver** | 8 (usamos 5: X, Y, Z, Z1, extrusor) |
| **Protocolo drivers** | UART (TMC2209) y SPI (TMC5160) simultáneo |
| **Entradas temperatura** | 4 termistores + 2 PT100/PT1000 |
| **Salidas calefactor** | 4 (usamos 2: hotend + cama) |
| **Salidas ventilador** | 6 PWM + 2 siempre encendidos |
| **Alimentación motores** | 12–60V independiente |
| **Precio aproximado** | ~60€ |

**¿Por qué la elegimos?**  
Necesitábamos una placa con capacidad para **8 drivers** (el formato 1×1m tiene múltiples motores), soporte simultáneo para TMC2209 (UART) y TMC5160 (SPI), y compatibilidad nativa con Klipper. La Octopus Pro cumple todo eso y tiene una comunidad enorme.

---

### BTT CB1 (ordenador de control)

| Campo | Valor |
|---|---|
| **CPU** | ARM Cortex-A55 (quad-core) |
| **RAM** | 1 GB DDR4 |
| **Almacenamiento** | microSD |
| **Sistema operativo** | Armbian + Klipper |
| **Interfaz web** | Fluidd |
| **Conexión con Octopus** | USB-C |

**¿Por qué no una Raspberry Pi?**  
El CB1 es más barato, monta directamente en la Octopus Pro (sin cables adicionales) y viene preconfigurado para Klipper. También es más fácil de conseguir en 2025-2026 que una RPi.

---

## Drivers de motor

### TMC2209 (UART) — para X, Y y extrusor

| Parámetro | Valor |
|---|---|
| **Corriente máxima** | 2A (run), 1.2A recomendado continuo |
| **Protocolo** | UART (1 solo cable de datos) |
| **StealthChop** | Sí (modo silencioso) |
| **Detección de carga** | StallGuard 4 |
| **Color en nuestra placa** | Azul |

Usamos TMC2209 para los ejes que usan **NEMA 17**: velocidad suficiente, bajo consumo, modo silencioso perfecto.

### TMC5160-T Pro (SPI) — para Z izquierdo y Z derecho

| Parámetro | Valor |
|---|---|
| **Corriente máxima** | 4.4A peak, 3A RMS |
| **Protocolo** | SPI (4 cables) |
| **StealthChop** | Sí |
| **Tensión** | 8–60V |
| **Color en nuestra placa** | Rojo |

**¿Por qué TMC5160 para Z y no TMC2209?**  
Los motores Z son **NEMA 23**, que necesitan **2A de corriente continua**. El TMC2209 solo aguanta ~1.2A de forma fiable. Si usáramos TMC2209 en Z, los motores se calentarían, perderían pasos, o el driver moriría.

---

## Motores

### NEMA 17 — Ejes X, Y (×3) y extrusor (×1)

- Paso: 1.8° (200 pasos/vuelta)
- Corriente run: 0.6A (X), 1.0A (Y), 0.85A (extrusor)
- Volumen 1m: necesitamos **2 motores en Y** en paralelo (ver [eje Y](cableado/eje-y.md))

### NEMA 23 — Eje Z (×2)

- Mayor fuerza de empuje para sostener la cama de 1m²
- Paso: 1.8°
- Corriente run: 2.0A (requiere TMC5160)
- **Dual Z independiente**: cada motor tiene su propio driver para poder hacer `Z_TILT_ADJUST`

### LDO-36STH20-1004AHG — Extrusor (dentro del SO3)

- Motor compacto integrado en el Smart Orbiter v3.0
- Corriente run: 0.85A

---

## Extrusor — LDO Smart Orbiter v3.0

| Campo | Valor |
|---|---|
| **Modelo** | LDO Smart Orbiter v3.0 (diseñado por Dr. Robert Lőrincz) |
| **Tipo** | Direct drive con reducción 7.5:1 |
| **rotation_distance calibrado** | 4.637 mm/rev |
| **Motor** | LDO-36STH20-1004AHG |
| **Sensor filamento** | Integrado |
| **Botón descarga** | Integrado |

**¿Por qué el Smart Orbiter v3.0?**  
Alta relación de reducción (7.5:1), muy ligero para un direct drive, sensor de filamento integrado y botón de descarga integrado. Es uno de los extrusores direct drive más recomendados para impresoras de gran formato.

---

## Sonda de nivelación — CR Touch (ALT04)

| Campo | Valor |
|---|---|
| **Modelo** | Creality CR Touch ALT04 |
| **Tipo** | Punta metálica servo-controlada |
| **Protocolo** | 5 hilos (compatible BL-Touch) |
| **Repetibilidad** | ±0.005 mm |

**¿Por qué CR Touch y no un final de carrera en Z?**  
Con una cama de 1m² es imposible nivelarla perfectamente a mano. El CR Touch + Klipper `BED_MESH_CALIBRATE` mapea 25 puntos (5×5) y compensa las imperfecciones de la cama automáticamente durante la impresión.

---

## Estructura mecánica

| Componente | Especificación |
|---|---|
| **Perfiles aluminio** | item 40×80mm, serie XMS, art. 0.0.669.99 |
| **Guías lineales** | MGN15R (carros R = rodamientos de bolas recirculantes) |
| **Husillo Z** | Métrico 12, paso 2mm, 4 entradas (= 8mm/rev) |
| **Correa XY** | GT2, 2mm paso, polea 20 dientes (= 40mm/rev) |

**¿Por qué MGN15R y no varillas lisas?**  
Para 1m de recorrido, las varillas lisas tienden a flectar en el centro. Las guías MGN15R son más rígidas y precisas.

**¿Por qué husillo T12 (métrico 12, 4 entradas)?**  
- `rotation_distance = paso × entradas = 2mm × 4 = 8mm/vuelta`
- Mayor avance por vuelta que T8 → menos pasos por mm, pero más velocidad Z
- Suficiente para una impresora (no necesitamos velocidad extrema en Z)

---

## Links de compra

- [BTT Octopus Pro V1.1 + CB1 (Amazon ES)](https://www.amazon.es/dp/B0BN7B6KV6)
- [Componente 2 (Amazon ES)](https://www.amazon.es/dp/B0CLLRG551)
- [Componente 3 (Amazon ES)](https://www.amazon.es/dp/B0D97P6Z64)
- [BTT Octopus Pro — Repositorio oficial](https://github.com/bigtreetech/BIGTREETECH-OCTOPUS-Pro)

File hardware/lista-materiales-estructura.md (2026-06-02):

# Lista de materiales — Estructura mecánica

> **Nota:** Esta lista está basada en los planos del proyecto. Para medidas exactas consultar el [PDF de planos estructurales](planos-estructurales.md) — generado con el configurador de item.

---

## Perfiles de aluminio item (40×80mm)

> Los perfiles son de la marca **item** (Industrietechnik), serie XMS, art. 0.0.669.99.  
> Perfil X 8 R40-90°, sección 40×80 mm, ranura 8 mm, taladro D6.8 M8 en extremos.

| Pieza | Cantidad | Longitud | Eje |
|---|---|---|-----|
| Perfil tipo 13v (frontal/trasero) | 3 | 1400 mm | Y |
| Perfil tipo 14v (lateral) | 1 | 1400 mm | X |
| Perfiles verticales (columnas) | 4 | 1400 mm | Z |
| Perfiles de refuerzo interior | ~4-8 | variable | — |

> Dimensión exterior del marco: **1441.5 mm** (1400 mm sin accesorios). Ver [planos estructurales](planos-estructurales.md).

---

## Guías lineales MGN15R

| Eje | Cantidad | Longitud |
|-----|---|---|
| X | 1 | ~1050mm |
| Y | 2 | ~1050mm |
| Z (vertical) | 2 | ~1100mm |

Carros incluidos con cada guía: tipo R (rodamientos de bolas recirculantes).

---

## Husillos trapezoidales (Eje Z)

| Especificación | Valor |
|---|---|
| Diámetro | M12 (métrica 12) |
| Paso | 2mm |
| Entradas | 4 (paso efectivo = 8mm/vuelta) |
| Longitud | ≥1200mm |
| Cantidad | 2 (uno por motor Z) |

---

## Motores paso a paso

| Motor | Cantidad | Eje | Modelo |
|---|---|-----|---|
| NEMA 17 | 3 | X (×1) + Y (×2) | Estándar 42mm |
| NEMA 23 | 2 | Z izq + Z der | 57mm, ≥2A |
| LDO-36STH20 (integrado SO3) | 1 | Extrusor | LDO especial |

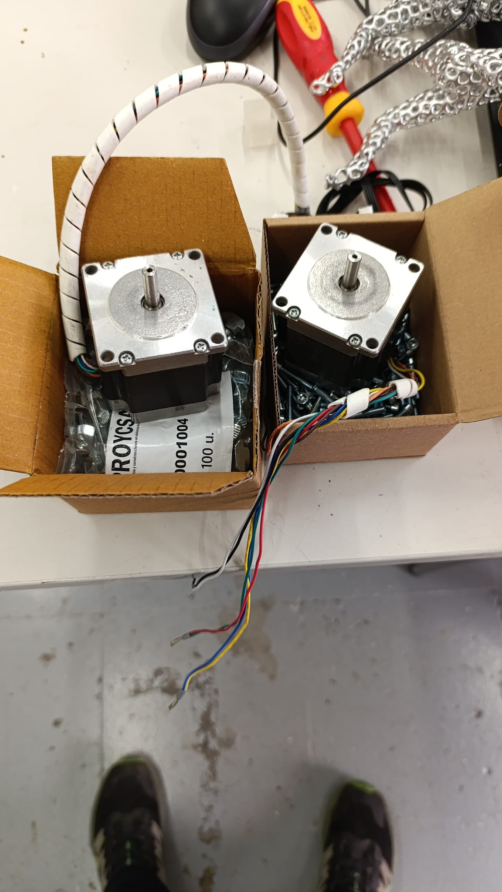
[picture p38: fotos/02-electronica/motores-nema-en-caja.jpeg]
Motores en caja

*Motores NEMA llegando en caja con tornillería incluida.*

---

## Correas y poleas (ejes X e Y)

| Componente | Especificación | Cantidad |
|---|---|---|
| Correa GT2 | 2mm paso, 6mm ancho | ~4m total (2m por eje) |
| Polea GT2 motriz | 20 dientes, eje 5mm | 3 (X + 2×Y) |
| Tensor / polea loca | GT2 sin dientes | ×4-6 |

---

## Tornillería

> Lista aproximada. Ver PDF de planos para cantidades exactas.

| Tornillo | Cantidad |
|---|---|
| M3×8 cabeza cilíndrica | ~100 |
| M3×12 | ~50 |
| M4×8 | ~80 |
| M4×12 | ~40 |
| Tuercas T M4 (para ranura perfil item (8mm)) | ~100 |
| M3 insert (para piezas impresas) | ~60 |

---

## Electrónica

| Componente | Cantidad | Observación |
|---|---|---|
| BTT Octopus Pro V1.1 (H723) | 1 | Placa principal |
| BTT CB1 | 1 | Ordenador de control |
| TMC2209 (azul) | 3 | Drivers X, Y, extrusor |
| TMC5160-T Pro (rojo) | 2 | Drivers Z izq + Z der |
| Fuente de alimentación 24V | 1 | ≥15A recomendado |
| Cama calefactada 500×500mm | 4 | 24V (montadas en paralelo cubriendo 1000×1000mm) |
| CR Touch ALT04 | 1 | Sonda nivelación |
| Final de carrera mecánico | 3 | X, Y, Z_max |

---

## Piezas impresas en 3D

Ver [hardware/piezas-impresas.md](piezas-impresas.md) para el catálogo completo.

| Tipo | Color | Cantidad aproximada |
|---|---|---|
| Soportes motor NEMA 23 (X/Y) | Verde | 4 |
| Tensores correa GT2 | Verde | 4-6 |
| Guías husillo (grises) | Gris | 4 |
| Portacables | Gris | ~20 |
| Soporte endstop | Gris | 3 |

**Conectores de perfil metálicos** (no impresos): conectores angulares + tuercas T para unir perfiles item 40×80mm y anclar guías lineales. Ver [fotos de conectores](../fotos/01-estructura/).

**Patas niveladoras con bloqueo:** 4 unidades. Permiten mover y fijar la estructura.

---

## Planos estructurales

> Archivo PDF del proyecto (planos del marco, medidas de corte de perfiles, posicionamiento de componentes):

📎 [BTT_Octopus_pro_EN.pdf](../BTT_Octopus_pro_EN.pdf) — Manual de la placa base

> **Pendiente**: Subir el PDF de planos estructurales del marco de aluminio (elaborado por el equipo del proyecto).

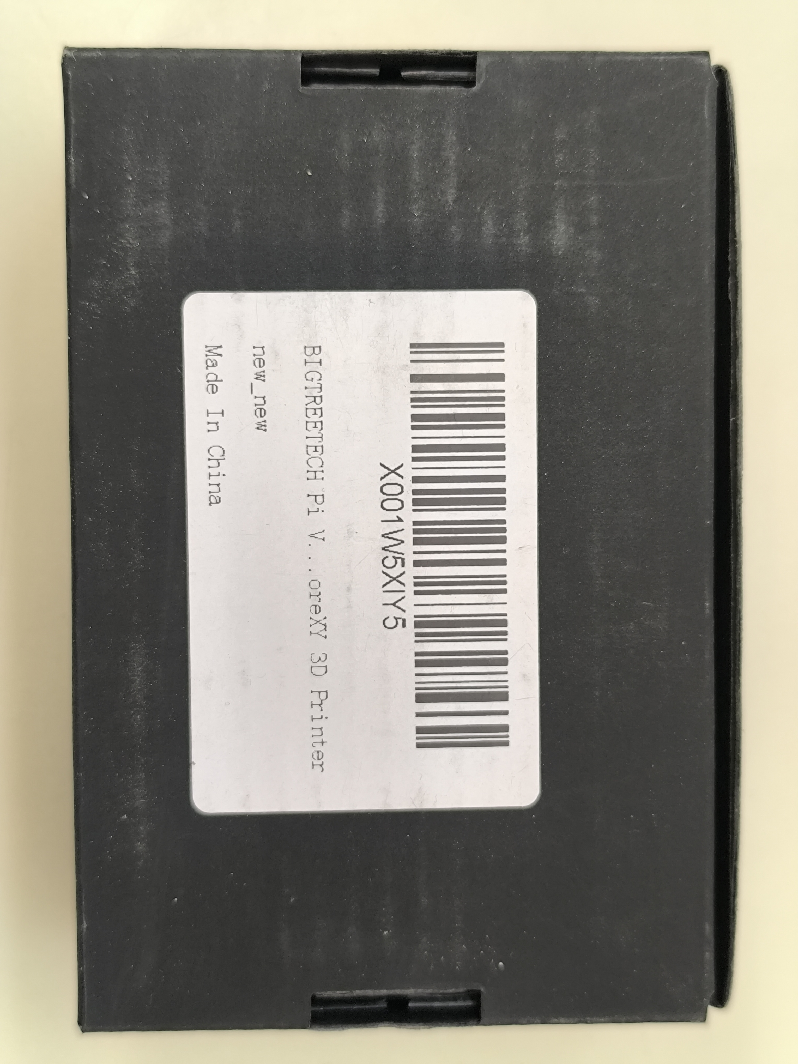
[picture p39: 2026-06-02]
fotos/06-cajas-componentes/caja-btt-pi-etiqueta.jpg

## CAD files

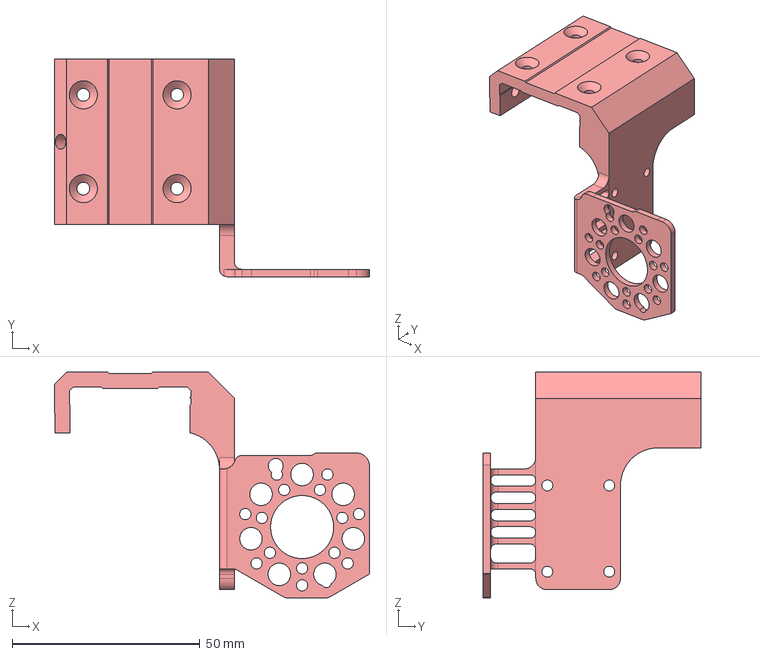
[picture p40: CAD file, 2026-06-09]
hardware/archivos-3d/Soporte carro de bolas PS 2-15 extrusor orbital (eje X) Nuevo (1).step
84.0 x 58.0 x 60.2 mm

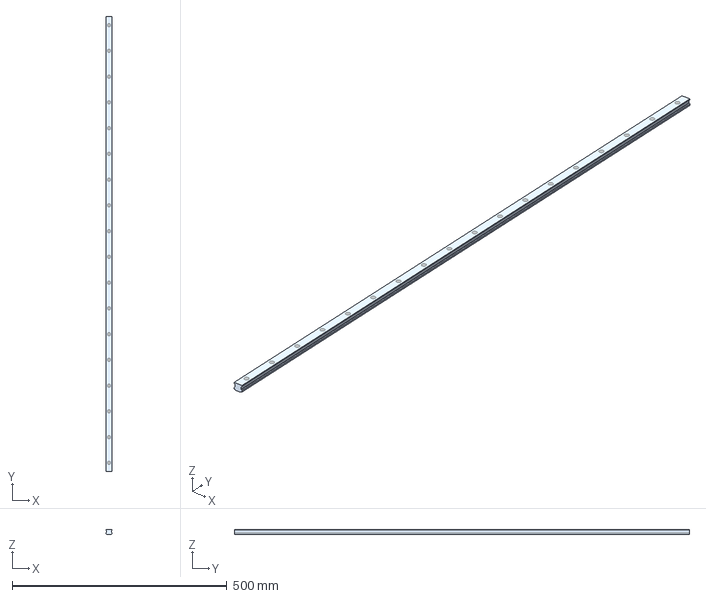
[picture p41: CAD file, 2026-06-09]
hardware/archivos-3d/item_44332_carril-guia-ps-4-15-4433_1060_high.step
15.0 x 1060.0 x 12.4 mm

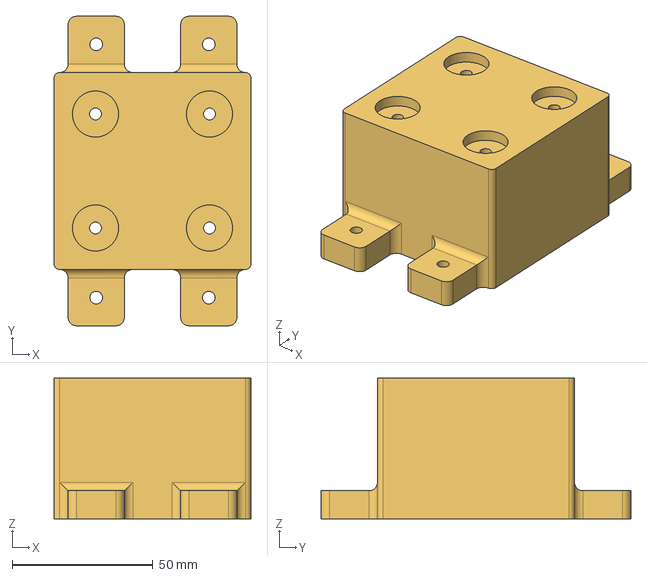
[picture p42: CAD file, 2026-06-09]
hardware/archivos-3d/Separador cuadruple cama caliente.step
70.0 x 110.0 x 50.0 mm

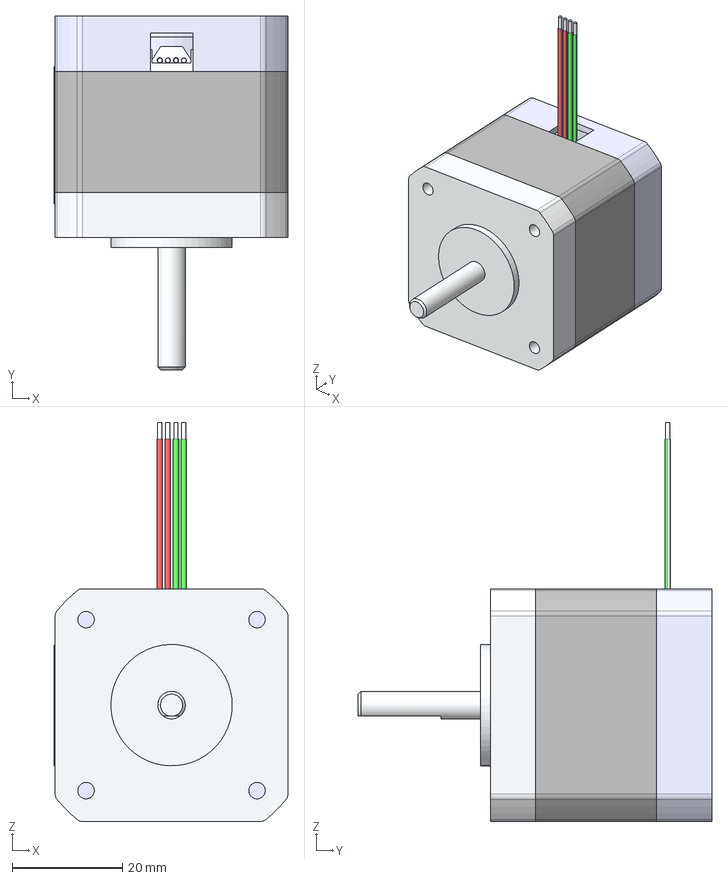
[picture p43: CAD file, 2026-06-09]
hardware/archivos-3d/Motor paso a paso 17H2041-100-4AL-1 eje x.step
42.4 x 64.1 x 72.4 mm

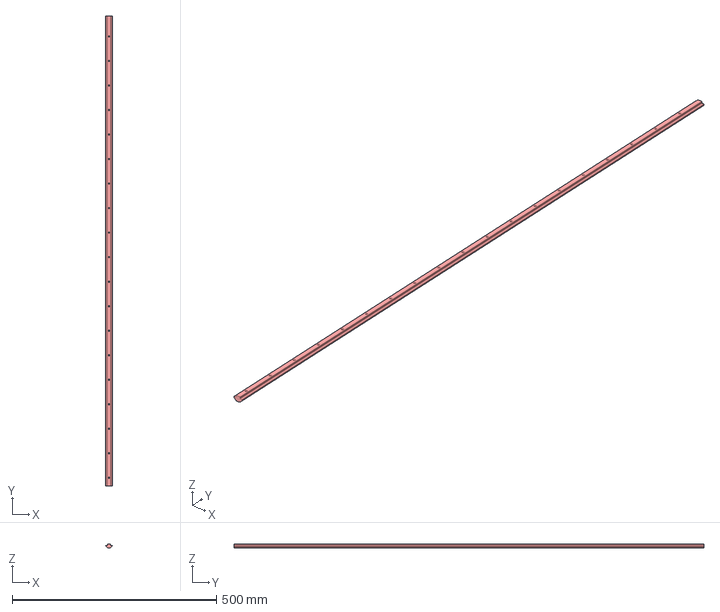
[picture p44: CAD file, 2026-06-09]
hardware/archivos-3d/item_44303_perfil-tuerca-8-al-m4-60_1150_high.step
16.0 x 1150.0 x 10.0 mm

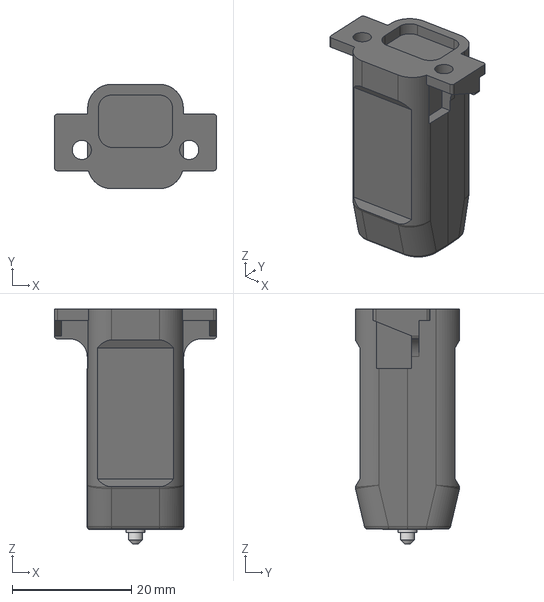
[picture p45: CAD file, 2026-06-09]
hardware/archivos-3d/CR-Touch-Dummy v1.step
27.2 x 17.5 x 39.4 mm

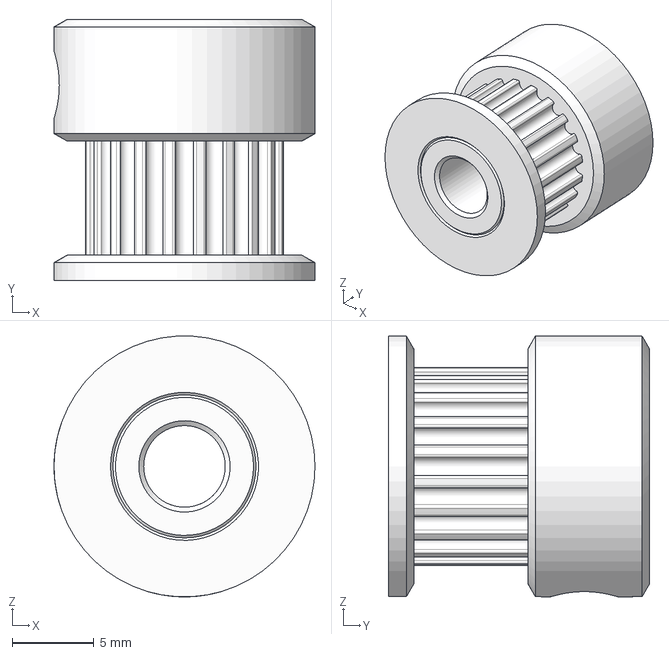
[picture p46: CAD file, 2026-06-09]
hardware/archivos-3d/GT2 polea dentada-20T-5mm agujero-correa 6mm-tornillo.step
16.0 x 16.0 x 16.0 mm

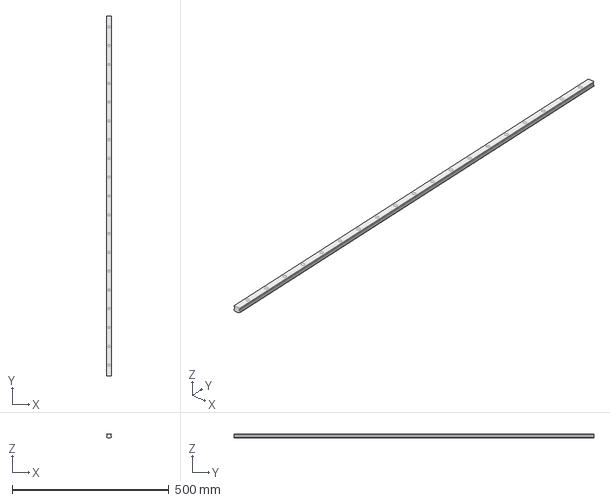
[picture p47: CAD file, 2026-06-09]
hardware/archivos-3d/item_44332_carril-guia-ps-4-15-4433_1150_high.step
15.0 x 1150.0 x 12.4 mm

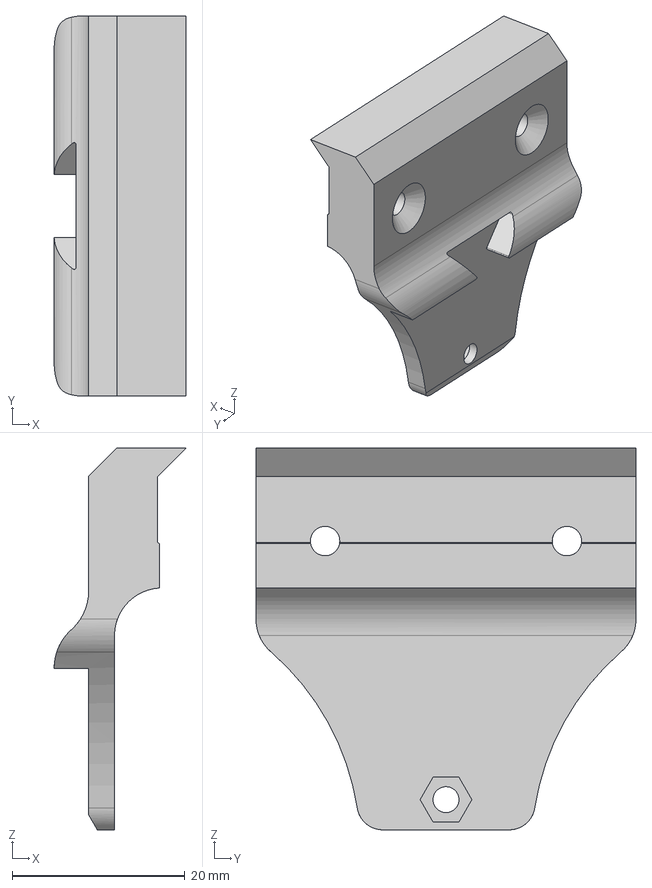
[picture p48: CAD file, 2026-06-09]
hardware/archivos-3d/Fijador correa eje X parte fija.step
15.3 x 44.0 x 44.2 mm

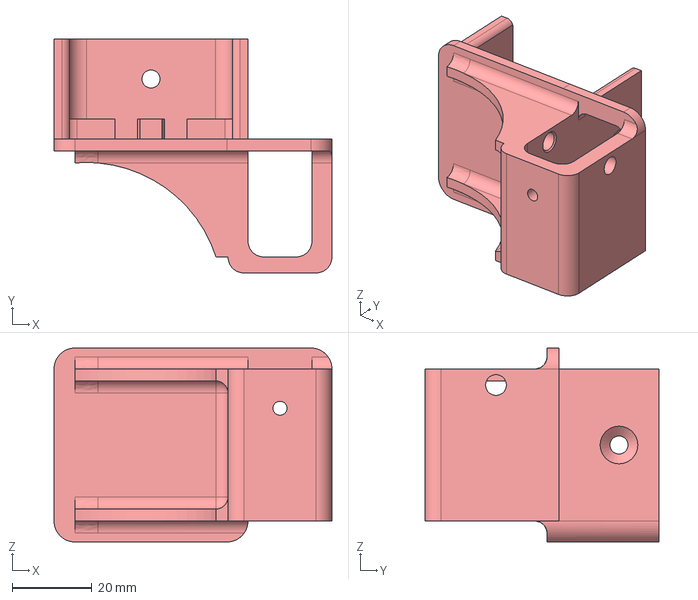
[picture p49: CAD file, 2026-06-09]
hardware/archivos-3d/soporte tensor eje Y (izquierdo) cuerpo.step
69.5 x 58.5 x 48.5 mm

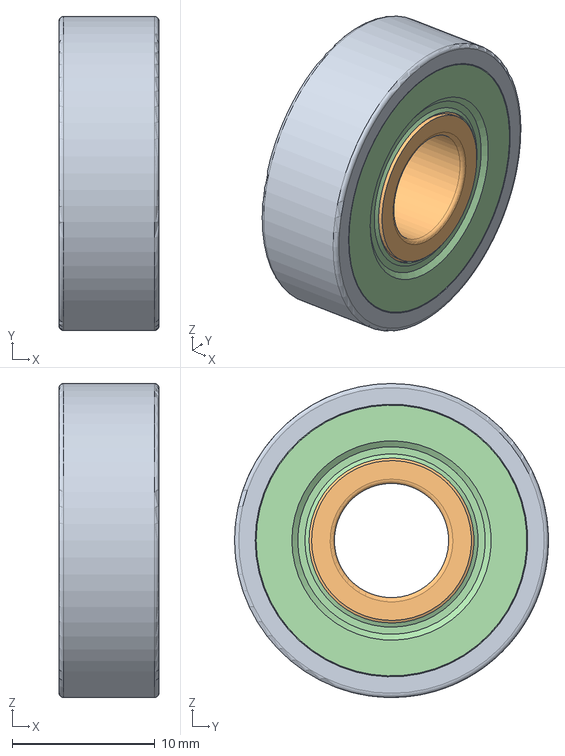
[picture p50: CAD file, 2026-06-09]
hardware/archivos-3d/Rodamiento de bolas de contacto radial con 2 juntas - para eje Ø8_608EEC3.step
7.00 x 22.0 x 22.0 mm

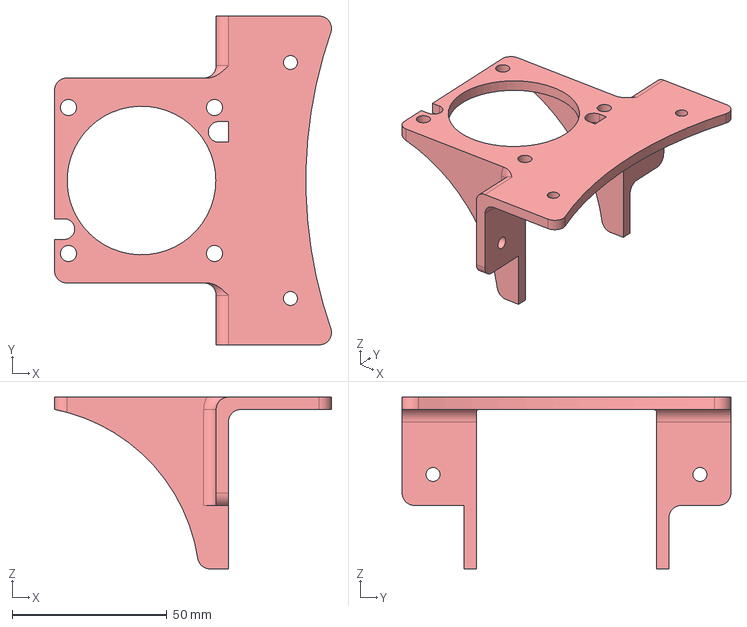
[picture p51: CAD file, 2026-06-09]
hardware/archivos-3d/Soporte motor eje Z.step
89.5 x 106.2 x 55.5 mm

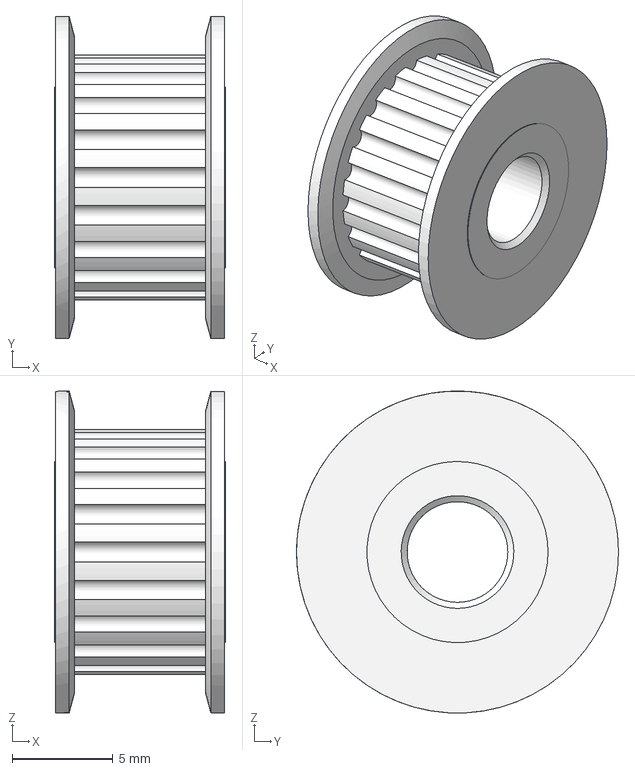
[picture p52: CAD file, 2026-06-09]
hardware/archivos-3d/Polea Gt2-20d Libre.step
8.50 x 16.0 x 16.0 mm

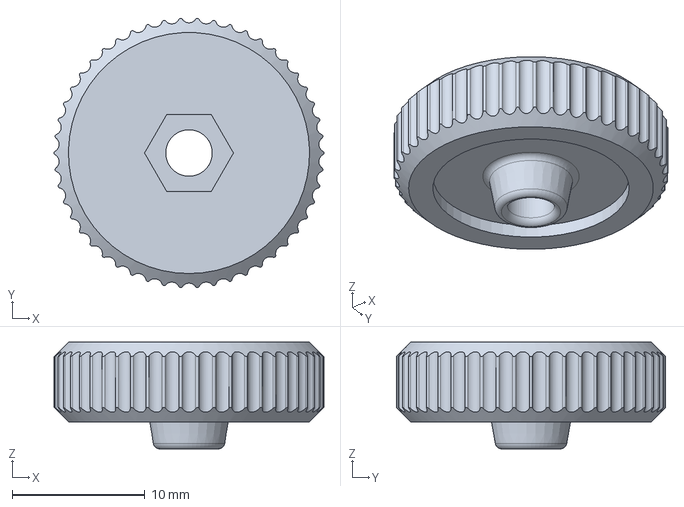
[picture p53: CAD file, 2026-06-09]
hardware/archivos-3d/Rueda de tensor pequeña eje X.step
20.3 x 20.3 x 8.03 mm

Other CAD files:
hardware/archivos-3d/Motor paso a paso 17H2041-100-4AL-1.step
hardware/archivos-3d/Nivelador TPU cama caliente.step
hardware/archivos-3d/eje polea libre brazo soporte tensor eje Y.step
hardware/archivos-3d/soporte tensor eje Y (derecho).step
hardware/archivos-3d/4010 turbo fan Creality DC Brushless CHA4024RM-10B.step
hardware/archivos-3d/Brazo soporte tensor eje Y.step
hardware/archivos-3d/Carro con recirculación de bolas PS 2-15 (eje X).step
hardware/archivos-3d/Carro recirculación bolas PS 4-15.step
hardware/archivos-3d/Eje polea elemento Tensor eje X.step
hardware/archivos-3d/Elemento polea Tensor eje X.step
hardware/archivos-3d/Fijador correa GT2 eje Y parte inferior.step
hardware/archivos-3d/Fijador correa GT2 eje Y superior.step
hardware/archivos-3d/Fijador correa eje X parte movil.step
hardware/archivos-3d/PLACAS ALUMINIO 500X500.step
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

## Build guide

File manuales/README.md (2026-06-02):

# Manuales y documentación oficial

> Manuales de todos los componentes del proyecto. Los PDFs disponibles están en esta carpeta; los demás se enlazan a la fuente oficial.

---

## BTT Octopus Pro V1.1

| Recurso | Enlace |
|---|---|
| **Manual oficial (EN)** | [BTT_Octopus_pro_EN.pdf](BTT_Octopus_pro_EN.pdf) *(incluido en este repositorio)* |
| **Repositorio GitHub oficial** | [github.com/bigtreetech/BIGTREETECH-OCTOPUS-Pro](https://github.com/bigtreetech/BIGTREETECH-OCTOPUS-Pro) |
| **Pinout completo** | [Octopus Pro Pinout (imagen oficial)](https://github.com/bigtreetech/BIGTREETECH-OCTOPUS-Pro/blob/master/Hardware/BIGTREETECH%20Octopus%20Pro%20V1.0-Pin.pdf) |

---

## BTT CB1 (ordenador de control)

| Recurso | Enlace |
|---|---|
| **Repositorio GitHub oficial** | [github.com/bigtreetech/CB1](https://github.com/bigtreetech/CB1) |
| **Imagen Armbian + Klipper** | [Releases CB1](https://github.com/bigtreetech/CB1/releases) |

---

## Klipper (firmware)

| Recurso | Enlace |
|---|---|
| **Documentación oficial** | [klipper3d.org/Overview.html](https://www.klipper3d.org/Overview.html) |
| **Instalación en CB1** | [klipper3d.org/Installation.html](https://www.klipper3d.org/Installation.html) |
| **Referencia printer.cfg** | [klipper3d.org/Config_Reference.html](https://www.klipper3d.org/Config_Reference.html) |

---

## LDO Smart Orbiter v3.0 (extrusor)

| Recurso | Enlace |
|---|---|
| **Página oficial LDO** | [ldomotors.com](https://www.ldomotors.com/product/so3) |
| **Documentación** | [docs.ldomotors.com/en/orbiter_v3](https://docs.ldomotors.com/en/orbiter_v3) |

---

## Drivers TMC

| Driver | Datasheet |
|---|---|
| **TMC2209** | [Trinamic TMC2209 Datasheet](https://www.trinamic.com/fileadmin/assets/Products/ICs_Documents/TMC2209_Datasheet_V103.pdf) |
| **TMC5160-T Pro** | [Trinamic TMC5160 Datasheet](https://www.trinamic.com/fileadmin/assets/Products/ICs_Documents/TMC5160A_Datasheet_Rev1.14.pdf) |

---

## CR Touch (sonda de nivelación)

| Recurso | Enlace |
|---|---|
| **Documentación Creality** | [Creality CR Touch](https://www.creality.com/products/creality-bl-touch) |
| **Configuración en Klipper** | [klipper3d.org/BLTouch.html](https://www.klipper3d.org/BLTouch.html) |

---

## item — Perfiles de aluminio

| Recurso | Enlace |
|---|---|
| **Catálogo perfil art. 0.0.669.99** | [item24.es](https://www.item24.es/es-es/art/perfil-x-8-40x80-natural-0-0-669-99.html) |
| **Planos estructurales del proyecto** | [hardware/planos-estructurales.md](../hardware/planos-estructurales.md) *(fotos de las 17 páginas)* |

---

## Fluidd (interfaz web de Klipper)

| Recurso | Enlace |
|---|---|
| **Documentación** | [docs.fluidd.xyz](https://docs.fluidd.xyz) |
| **Repositorio** | [github.com/fluidd-core/fluidd](https://github.com/fluidd-core/fluidd) |

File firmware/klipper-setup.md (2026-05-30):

# Instalación y configuración de Klipper

> Guía para instalar Klipper en el BTT CB1 y flashear el firmware en la BTT Octopus Pro V1.1 (STM32H723).

---

## Arquitectura del sistema

```
CB1 (ARM Linux) ─── USB-C ─── Octopus Pro (STM32H723)
      │                              │
      │ Klipper host                 │ Klipper MCU firmware
      │ Fluidd (web UI)              │ Gestiona: motores, temp, fans
      │                              │
  microSD                        Flash interna
```

El CB1 corre el **host de Klipper** (Python) y se comunica con el **firmware de Klipper** en el STM32 de la Octopus Pro vía USB. Fluidd es la interfaz web para controlar la impresora desde el navegador.

---

## Paso 1: Imagen del CB1

1. Descargar la imagen de BTT CB1 con Klipper preinstalado desde el repositorio oficial de BigTreeTech
2. Flashear la microSD con **Balena Etcher** o **Raspberry Pi Imager**
3. Insertar la microSD en el slot del CB1
4. La imagen ya incluye: Klipper + Moonraker + Fluidd + KlipperScreen

---

## Paso 2: Compilar y flashear el firmware para el STM32H723

### Configuración de compilación

```bash
cd ~/klipper
make menuconfig
```

En el menú seleccionar:
- **Micro-controller Architecture:** STMicroelectronics STM32
- **Processor model:** STM32H723
- **Bootloader offset:** 128KiB bootloader
- **Clock Reference:** 25 MHz crystal
- **Communication interface:** USB (on PA11/PA12)

```bash
make clean
make
```

Esto genera `out/klipper.bin`.

### Método de flasheo: SD card

1. Renombrar `klipper.bin` a `firmware.bin`
2. Copiar a una microSD formateada en FAT32
3. Insertar la SD en el slot de la **Octopus Pro** (no en el CB1)
4. Encender la placa — el bootloader carga el firmware automáticamente
5. El LED parpadea durante el flasheo, luego queda fijo

### Verificar que el firmware cargó

```bash
ls /dev/serial/by-id/
# Debe aparecer: usb-Klipper_stm32h723xx_XXXX-if00
```

---

## Paso 3: Configurar printer.cfg

El archivo de configuración principal está en:
```
~/printer_data/config/printer.cfg
```

Copiar el `printer.cfg` de este repositorio como punto de partida.

Actualizar el serial del MCU:
```ini
[mcu]
serial: /dev/serial/by-id/usb-Klipper_stm32h723xx_XXXXXXXX-if00
```
(El ID exacto varía por placa — usar el `ls /dev/serial/by-id/` para obtenerlo)

---

## Paso 4: Acceder a Fluidd

Una vez todo conectado:

1. La Octopus Pro conectada al CB1 por USB-C
2. El CB1 conectado a la red WiFi
3. Abrir el navegador y acceder a la IP del CB1 (ej: `http://192.168.1.XX`)

Fluidd muestra:
- Estado de la impresora en tiempo real
- Temperatura de hotend y cama
- Controles de movimiento manual
- Consola para enviar comandos G-code

---

## Comandos de prueba inicial

```gcode
# Verificar temperatura (sin calentar)
M105

# Mover eje X sin hacer home (para probar)
SET_KINEMATIC_POSITION X=100 Y=100 Z=10
G1 X200 F3000

# Test de extrusor (forzado, hotend frío)
SET_KINEMATIC_POSITION X=100 Y=100 Z=10
# (con min_extrude_temp: 0 temporalmente)

# Home completo
G28

# Calibración Z con CR Touch
PROBE_CALIBRATE

# Z_TILT (ecualizar los dos motores Z)
Z_TILT_ADJUST

# Mapa de cama
BED_MESH_CALIBRATE
```

---

## Estructura de archivos de Klipper en el CB1

```
~/printer_data/
├── config/
│   ├── printer.cfg          # Configuración principal
│   └── moonraker.conf       # Config de la API web
├── gcodes/                  # Archivos G-code para imprimir
├── logs/                    # Logs del sistema
└── database/                # Base de datos de Klipper
```

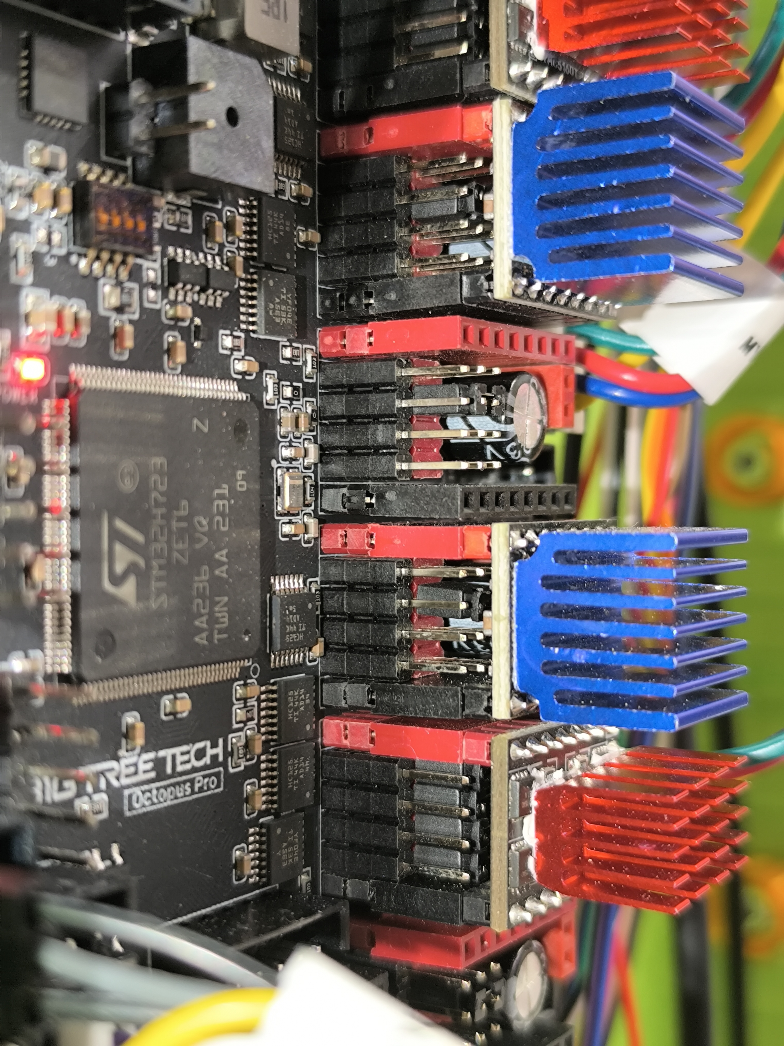
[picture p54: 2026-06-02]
fotos/05-montaje-electronica/octopus-pro-drivers-etiqueta.jpg

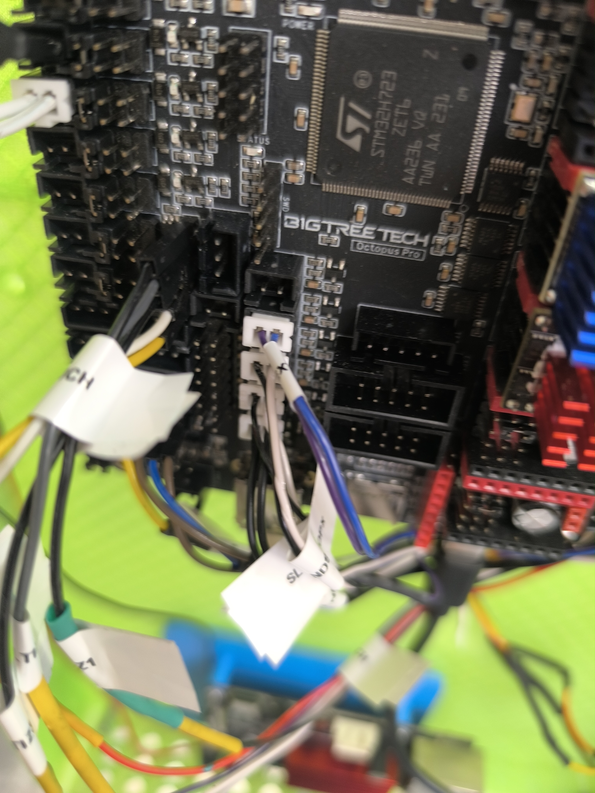
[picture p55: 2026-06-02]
fotos/05-montaje-electronica/octopus-pro-chip-stm32.jpg

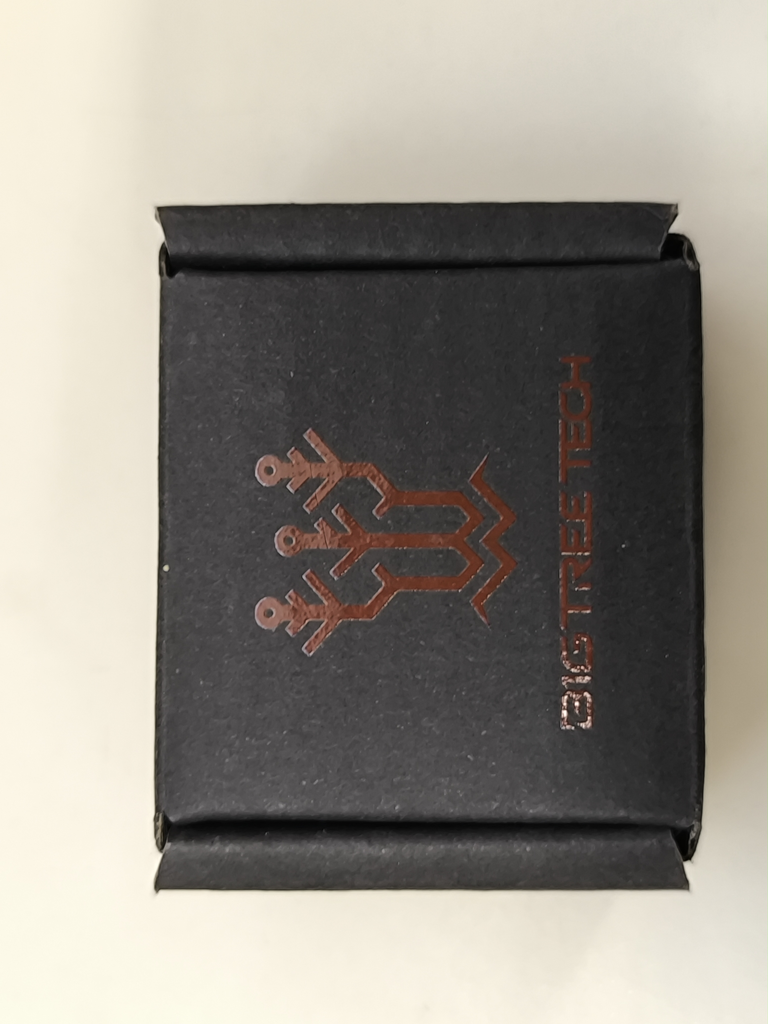
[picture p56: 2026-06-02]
fotos/06-cajas-componentes/caja-btt-for-makers.jpg

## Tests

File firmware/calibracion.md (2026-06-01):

# Calibración — PID, Z offset, Bed Mesh, Z_TILT

> Todos los pasos de calibración necesarios para una impresión correcta.

---

## 1. PID del hotend

El PID controla el calefactor del hotend para mantener la temperatura estable.

### Procedimiento

```gcode
PID_CALIBRATE HEATER=extruder TARGET=220
SAVE_CONFIG
```

Klipper oscila la temperatura y calcula los valores óptimos K_p, K_i, K_d. Los guarda automáticamente en `printer.cfg`.

### Nuestros valores calibrados

```ini
#*# [extruder]
#*# control = pid
#*# pid_kp = 22.602
#*# pid_ki = 1.408
#*# pid_kd = 90.690
```

---

## 2. PID de la cama (pendiente)

Una vez instalado el termistor:

```gcode
PID_CALIBRATE HEATER=heater_bed TARGET=60
SAVE_CONFIG
```

---

## 3. Z_TILT_ADJUST — Nivelación dual Z

Iguala los dos motores Z para que la cama quede perfectamente horizontal.

### Procedimiento

```gcode
G28         # Home completo primero
Z_TILT_ADJUST
```

Klipper:
1. Sondea el punto izquierdo de la cama
2. Sondea el punto derecho
3. Calcula la diferencia de altura
4. Ajusta independientemente cada motor Z

### Configuración

```ini
[z_tilt]
z_positions:
    -50, 150    # Posición física del husillo izquierdo
    350, 150    # Posición física del husillo derecho
points:
    30, 150     # Punto de sondeo izquierdo
    270, 150    # Punto de sondeo derecho
speed: 50
horizontal_move_z: 5
```

---

## 4. Z Offset — Distancia boquilla-cama

Calibra la distancia exacta entre la boquilla y la cama cuando el CR Touch detecta el "cero".

### Procedimiento

```gcode
G28
PROBE_CALIBRATE
```

Usa el **método del papel**:
1. Coloca un folio debajo de la boquilla
2. Baja con `TESTZ Z=-0.05` hasta que el papel tenga ligera resistencia
3. Confirma con `ACCEPT`
4. Guarda con `SAVE_CONFIG`

```gcode
# Comandos de ajuste fino:
TESTZ Z=-0.1    # bajar 0.1mm
TESTZ Z=+0.05   # subir 0.05mm
TESTZ Z=-0.025  # micro-ajuste
```

> El z_offset real se guarda en `#*# SAVE_CONFIG`. Varía según el montaje físico del CR Touch.

---

## 5. Bed Mesh — Mapa de la cama

Mapea la superficie completa de la cama y compensa las irregularidades en tiempo real.

### Procedimiento

```gcode
G28
Z_TILT_ADJUST    # siempre antes del bed mesh
BED_MESH_CALIBRATE
SAVE_CONFIG
```

Con `probe_count: 5, 5`, el CR Touch sondea **25 puntos** en una cuadrícula 5×5 entre `mesh_min: 30,30` y `mesh_max: 970,970`.

### Activar en cada impresión

La macro START_PRINT lo hace automáticamente:

```ini
[gcode_macro START_PRINT]
gcode:
  G28
  Z_TILT_ADJUST
  BED_MESH_CALIBRATE
  # ... resto de la secuencia
```

---

## 6. Calibración del extrusor (rotation_distance)

```gcode
# 1. Temperatura mínima para extruir
M109 S200

# 2. Marcar filamento a 100mm de la entrada del extrusor
# 3. Extruir exactamente 100mm
G92 E0
G1 E100 F100

# 4. Medir cuánto filamento entró realmente (con regla)
# Ejemplo: entró 97.3mm en lugar de 100mm

# 5. Calcular nuevo rotation_distance:
# nuevo = actual × (pedido / medido)
# 4.637 × (100 / 97.3) = 4.76 → actualizar en printer.cfg
```

Nuestro valor final calibrado: **`rotation_distance: 4.637`**

---

## 7. Calibración de impresión — Piezas de prueba

Una vez calibrado el firmware, hay que verificar que la impresora produce piezas correctas dimensionalmente.

### Cubo de calibración 20×20×20mm

Imprimir un cubo de 20×20×20mm y medirlo con calibre:

```
Objetivo: 20.0mm en X, Y y Z
Tolerancia aceptable: ±0.2mm
```

Si hay desviación:
- **X/Y**: ajustar `rotation_distance` del stepper correspondiente
- **Z**: ajustar `rotation_distance` del husillo (actualmente 8mm/vuelta)
- **Extrusor (desbordamiento/hueco)**: ajustar `rotation_distance` del extrusor

### Benchy (3DBenchy)

Imprimir el modelo estándar de referencia [3DBenchy](https://www.3dbenchy.com/). Evaluar:
- Puentes sin soporte (zona de la cabina)
- Voladizos
- Texto en relieve
- Tolerancias en orificios circulares

### Archivos STL de tolerancias

Imprimir piezas de ajuste (tolerance test) para medir holguras reales entre piezas ensambladas. Útil antes de imprimir piezas funcionales con tolerancias precisas.

---

## Orden de calibración recomendado

1. Flashear firmware
2. Copiar `printer.cfg` base
3. Verificar que todos los motores se mueven correctamente
4. `PID_CALIBRATE` hotend
5. `G28` (home completo)
6. `PROBE_CALIBRATE` (z_offset)
7. `Z_TILT_ADJUST`
8. `BED_MESH_CALIBRATE`
9. Calibrar extrusor (rotation_distance)
10. `PID_CALIBRATE` cama (cuando se instale el termistor)

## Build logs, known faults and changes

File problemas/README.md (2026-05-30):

# Problemas encontrados y soluciones

> Esta sección documenta todos los problemas reales que encontramos durante la construcción y cómo los resolvimos. Está ordenada cronológicamente.

---

## Índice

| # | Problema | Impacto | Estado |
|---|---|---|---|
| 1 | [Slot MOTOR 3 defectuoso](motor-z-slot-defectuoso.md) | Z derecho no funcionaba | ✅ Resuelto |
| 2 | [Cable motor Y mal conectado](eje-y-dual.md) | Motor Y no se movía | ✅ Resuelto |
| 3 | [Ventilador hotend no se apagaba](ventilador-hotend.md) | Ventilador siempre encendido | ✅ Resuelto |
| 4 | [Endstop Z — configuración incorrecta](endstop-z.md) | Z no paraba en tope superior | ✅ Resuelto |
| 5 | [CR Touch — z_offset obligatorio](crtouch-z-offset.md) | Klipper no arrancaba | ✅ Resuelto |
| 6 | [Termistor cama no instalado](termistor-cama.md) | Temperatura cama incorrecta | ⚠️ Pendiente |
| 7 | [Husillo de 1.2m difícil de encontrar](husillo-trapezoidal.md) | Cuello de botella en construcción | ✅ Resuelto |
| 8 | [Calentador subía solo a 220°C](calentador-runaway.md) | Riesgo de thermal runaway | ✅ Resuelto |

---

## Lecciones aprendidas

1. **Probar el hardware antes de montarlo** — el slot MOTOR 3 estaba defectuoso de fábrica. Siempre testar los slots con un motor y un driver antes de asumir que funciona.

2. **El cable siempre es sospechoso** — cuando un motor no se mueve, antes de cambiar la configuración, comprueba el cableado físico.

3. **UART vs SPI no es intercambiable** — TMC2209 y TMC5160 usan protocolos completamente diferentes. Mezclarlos en la configuración causa errores silenciosos difíciles de depurar.

4. **Klipper exige `z_offset` en bltouch antes de arrancar** — añade `z_offset: 0` temporalmente y calibra después con `PROBE_CALIBRATE`.

5. **La cama calefactada necesita termistor real** — usar `min_temp: -110` como parche sirve para probar, pero no da información real de temperatura.

6. **`dir_pin: !PF0`** — la `!` antes del pin invierte la dirección. Cuando un motor gira al revés, añade o quita la `!` en lugar de mover los cables.

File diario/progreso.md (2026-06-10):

# Diario del proyecto

> Cronología completa: desde los primeros componentes en febrero hasta la impresora de 1m³ funcionando.

---

## Fase 0 — Recepción de componentes y primeras inspecciones (Febrero 2026)

### 25 de febrero — Llega la Octopus Pro

Recibimos la BTT Octopus Pro V1.1 y la inspeccionamos antes de conectar nada.

Trasera Octopus Pro
*Vista trasera de la placa recién recibida. Se pueden leer claramente todos los slots: MOTOR0, MOTOR1, MOTOR2_1, MOTOR2_2... hasta MOTOR7. Versión: 1.1.*

También inspeccionamos la zona del USB-C y el conector de la fuente de alimentación.

**Primer paso:** Identificar todos los slots de driver y planificar qué motor va en cada slot antes de conectar nada.

---

## Fase 1 — Montaje de la estructura (Febrero–Marzo 2026)

El primer paso real del proyecto fue cortar y montar el **marco de perfiles de aluminio item 40×80mm**.

### Materiales de la estructura
- Perfiles item 40×80mm cortados a medida (ver [lista de materiales](../hardware/lista-materiales-estructura.md))
- Conectores angulares metálicos para unir los perfiles en esquinas
- Tornillería M3 y M4 con tuercas T en ranura del perfil

### Piezas impresas para la estructura

Durante esta fase se imprimieron todas las piezas en 3D necesarias:

Piezas en aula
*Todas las piezas impresas listas en el aula: soportes de motor verdes y guías grises.*

Soportes grandes NEMA23
*Soportes para los 4 motores NEMA 23 del eje Z.*

Tensores y soportes
*Tensores de correa GT2 y soportes impresos.*

---

## Fase 2 — Primera electrónica: testeo de la placa (Abril 2026)

### 8 de abril — Primeras conexiones

Conectamos los primeros componentes a la Octopus Pro para probar que la placa funcionaba antes de montarla en la estructura.

CR Touch ALT04
*CR Touch modelo ALT04 con sus 5 cables de colores.*

Cable hotend etiquetado
*Cables del hotend identificados: termistor ATC Semitec 104NT-4 y calentador cerámico 24V 72W.*

Octopus Pro overview
*Vista general de la placa con drivers instalados: TMC5160 rojos (Z) y TMC2209 azules (X, Y, extrusor).*

### 10 de abril — Primer arranque con CR Touch

Conectamos el CR Touch a la placa y arrancamos Klipper por primera vez.

Primer test electronica
*Placa conectada a la fuente de alimentación y al CR Touch para el primer test.*

**Problema encontrado:** Klipper no arrancaba porque faltaba `z_offset: 0` en la sección `[bltouch]`.  
→ Ver [crtouch-z-offset.md](../problemas/crtouch-z-offset.md)

### 10 de abril — Test de motores

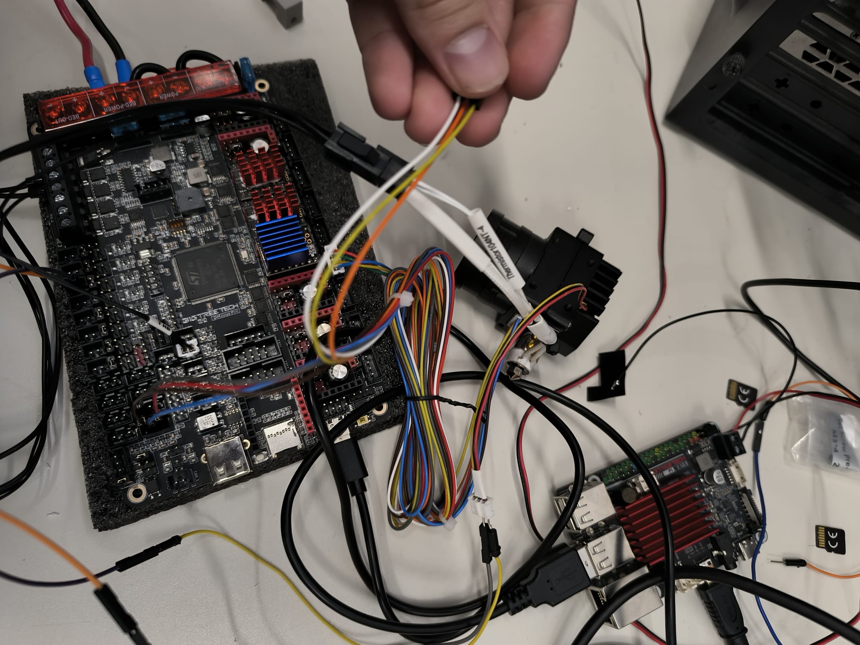
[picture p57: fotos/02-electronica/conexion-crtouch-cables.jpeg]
Conexion CR Touch

*Conectando los cables del CR Touch a los pines PB6 y PB7 de la Octopus Pro.*

---

## Fase 3 — Problemas de hardware (Abril 2026)

### Slot MOTOR 3 defectuoso

Descubrimos que el slot MOTOR 3 de la placa estaba **defectuoso de fábrica**. El motor Z derecho no respondía.

**Diagnóstico:** Probamos el driver en otros slots — funcionaba. Probamos el motor en otros slots — funcionaba. El slot MOTOR 3 estaba muerto.

**Solución:** Mover el motor Z derecho al slot **MOTOR 5** y actualizar `printer.cfg`.

→ Ver [motor-z-slot-defectuoso.md](../problemas/motor-z-slot-defectuoso.md)

### Motor Y no se movía

El motor Y no respondía. Diagnóstico rápido: **el cable JST no estaba bien conectado**.

**Lección:** Antes de cambiar configuración, revisar siempre el cable físico.

→ Ver [eje-y-dual.md](../problemas/eje-y-dual.md)

---

## Fase 4 — Cableado completo (23 de abril 2026)

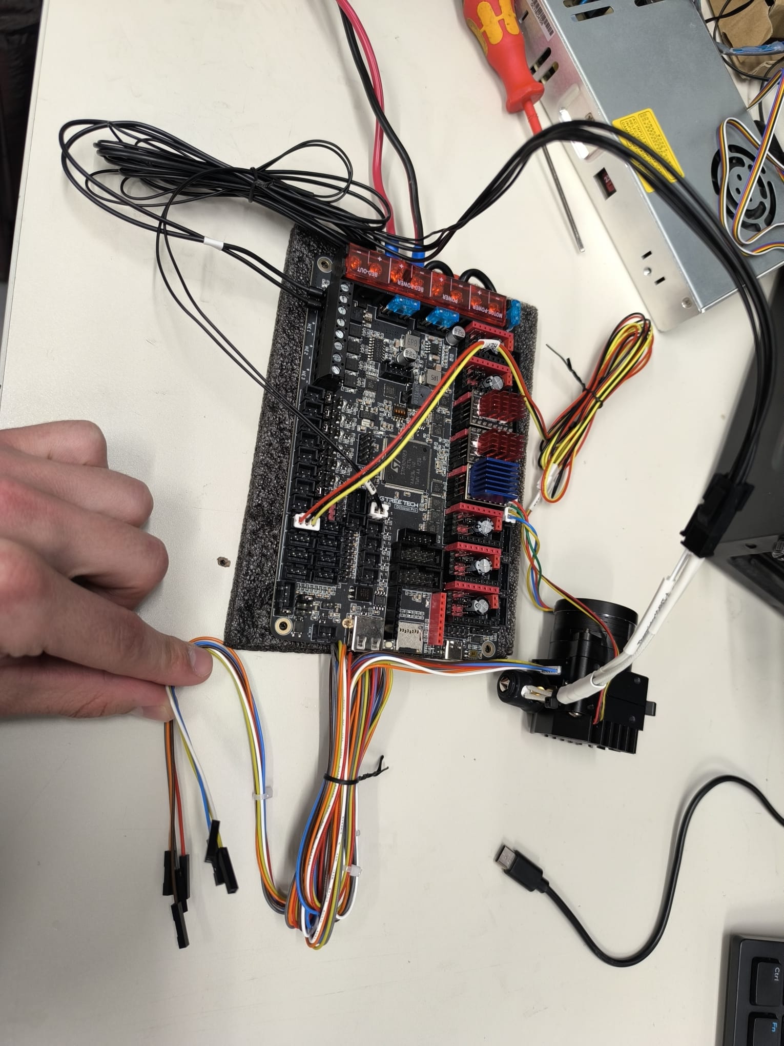
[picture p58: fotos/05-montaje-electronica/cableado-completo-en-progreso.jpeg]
Cableado completo en progreso

*Sesión de cableado: todos los motores, sensores y calefactores conectados a la placa.*

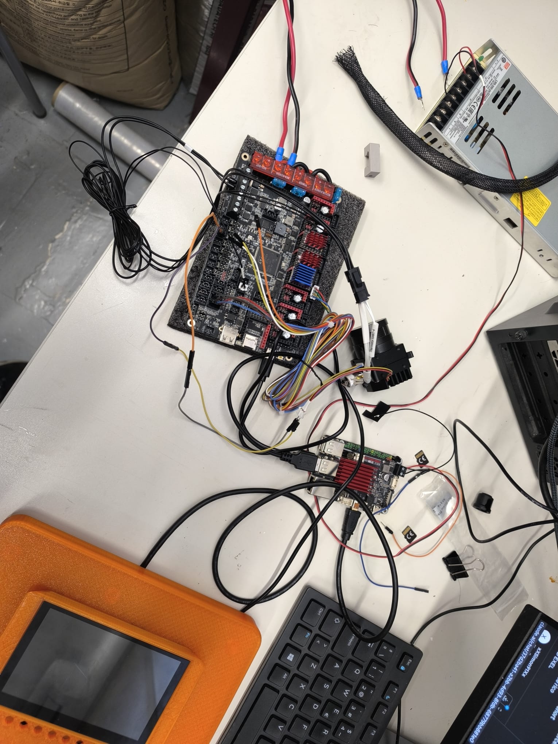
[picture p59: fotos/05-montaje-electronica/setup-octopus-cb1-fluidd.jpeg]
Setup completo con Fluidd

*Setup de trabajo: Octopus Pro + CB1 + teclado + pantalla con Fluidd. La tablet naranja es la pantalla KlipperScreen.*

### Problemas de ventilación

El ventilador del heatsink del SO3 no se apagaba nunca. La causa: estaba configurado como `[fan]` (ventilador de capa) en lugar de `[heater_fan]`.

→ Ver [ventilador-hotend.md](../problemas/ventilador-hotend.md)

---

## Fase 5 — Primer arranque de Klipper

Fluidd configuración inicial
*Primer arranque con errores de configuración. Fluidd muestra los avisos de printer.cfg que hay que corregir antes de poder mover nada. La tablet naranja (KlipperScreen) ya está activa.*

Fluidd funcionando
*¡Klipper funcionando! Fluidd mostrando la interfaz completa en el monitor Dell. A la izquierda el rack de electrónica con todo conectado.*

Setup completo con KlipperScreen
*Setup de desarrollo completo: monitor Dell con Fluidd, KlipperScreen naranja en la mesa y toda la electrónica montada a la izquierda.*

En el monitor se ve la interfaz de Fluidd con:
- Temperatura del hotend y la cama
- Controles de movimiento XYZ
- Consola para comandos G-code
- Estado de la impresora

La tablet naranja en la mesa es la **BTT KlipperScreen** — pantalla táctil para controlar la impresora sin necesidad de un PC.

---

## Fase 6 — Montaje en la estructura (Mayo 2026)

### 22 de abril — Guías lineales y carro

Instalamos las guías lineales MGN15R en el eje Y:

Guía lineal montada
*Guía MGN15R con carro instalada en el perfil item 40×80mm.*

Soporte motor con polea
*Soporte de motor impreso (verde) montado sobre el perfil item 40×80mm. La polea loca naranja guía la correa GT2. En la parte superior se ven los tensores impresos también en naranja.*

### 13 de mayo — Husillo y eje Z

Instalamos los husillos trapezoidales M12 de 1200mm con sus soportes impresos:

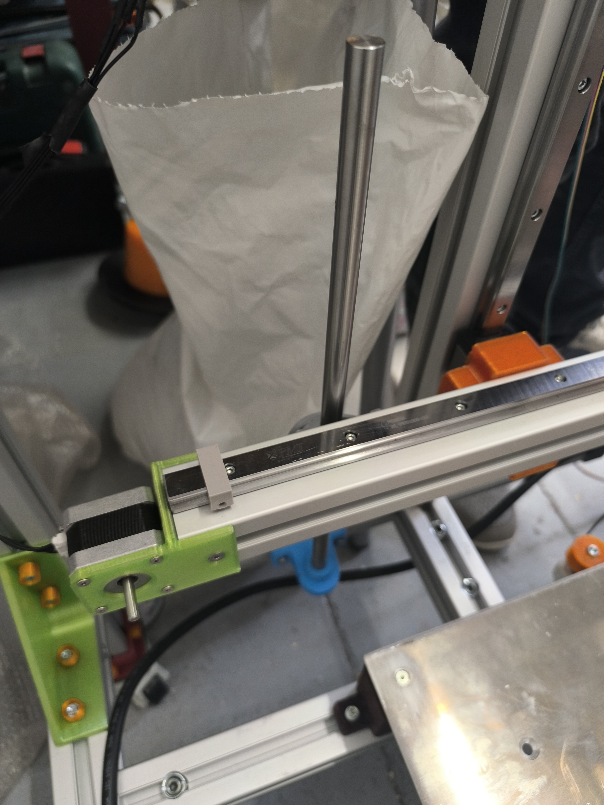
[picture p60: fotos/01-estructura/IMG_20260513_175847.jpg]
Husillo y perfil

*Husillo M12 (4 entradas, 8mm/vuelta) instalado en el perfil vertical del eje Z.*

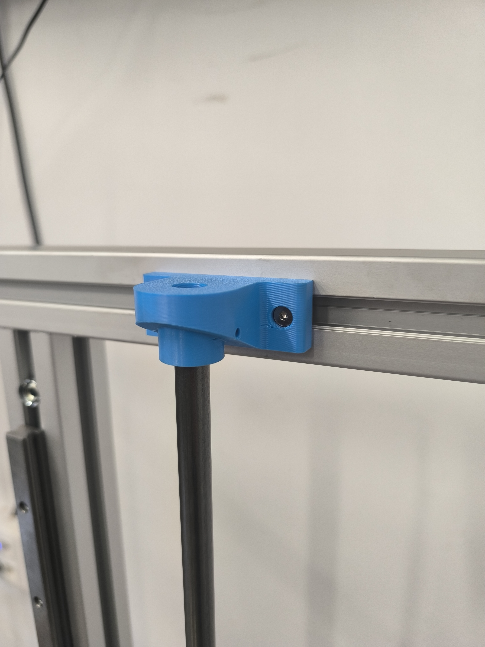
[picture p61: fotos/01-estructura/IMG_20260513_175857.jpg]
Soporte husillo

*Soporte impreso en azul para el extremo superior del husillo.*

---

## Fase 7 — Integración final del cabezal

Cables extrusor montados
*Mazo de cables del cabezal ya instalado en la impresora. Los cables están etiquetados como "EXTRUSOR" para facilitar el mantenimiento.*

---

## Fase 8 — Cableado completo y etiquetado (1 junio 2026)

### 1 de junio — Sesión de cableado final

Sesión completa de conexión de todos los cables al panel de electrónica verde. Se etiquetaron todos los conectores antes de enchufar.

**Sistema de etiquetado de cables:**

| Etiqueta | Cable |
|---|---|
| `MY1` | Motor Y izquierdo (MOTOR2_1) |
| `MY2` | Motor Y derecho (MOTOR2_2, paralelo) |
| `MX` | Motor X (MOTOR0) |
| `MZ1` | Motor Z izquierdo (MOTOR1) |
| `MZ2` | Motor Z derecho (MOTOR5) |
| `BLTOU` | Cable de control CR Touch (servo, PB6) |
| `NDSTOPZ` | Endstop Z máximo (PF7) |
| `NDSTOPX` | Endstop X (PF5) |
| `BED` | Cables cama calefactada (pendiente) |

Panel electrónica completo
*Panel verde con Octopus Pro + CB1 completamente cableado. Todos los conectores llevan etiquetas impresas.*

Drivers y cables etiquetados
*Detalle de los drivers con cables etiquetados saliendo hacia los motores.*

KlipperScreen y electrónica
*La pantalla KlipperScreen (carcasa naranja impresa en 3D) instalada junto al panel de electrónica en la máquina.*

### Incidente — Cable de endstop roto

Durante el proceso de etiquetado se encontró un cable de endstop con el extremo pelado (sin terminal). Se resoldó y se crimpó un terminal nuevo.

**Lección**: siempre revisar la continuidad de los cables de endstop antes de energizar.

---

## Fase 9 — Máquina completamente ensamblada (5 junio 2026)

La impresora está **de pie y operativa** en el taller del Institut Jaume Huguet. Esta es la primera vez que la máquina se ve completamente montada en su ubicación final.

### Estado del montaje

Máquina completa — vista frontal
*Impresora 3D de 1000×1000×1000mm completamente ensamblada en el taller. Altura total aproximada 1.5m. KlipperScreen (naranja) montado en el perfil lateral derecho.*

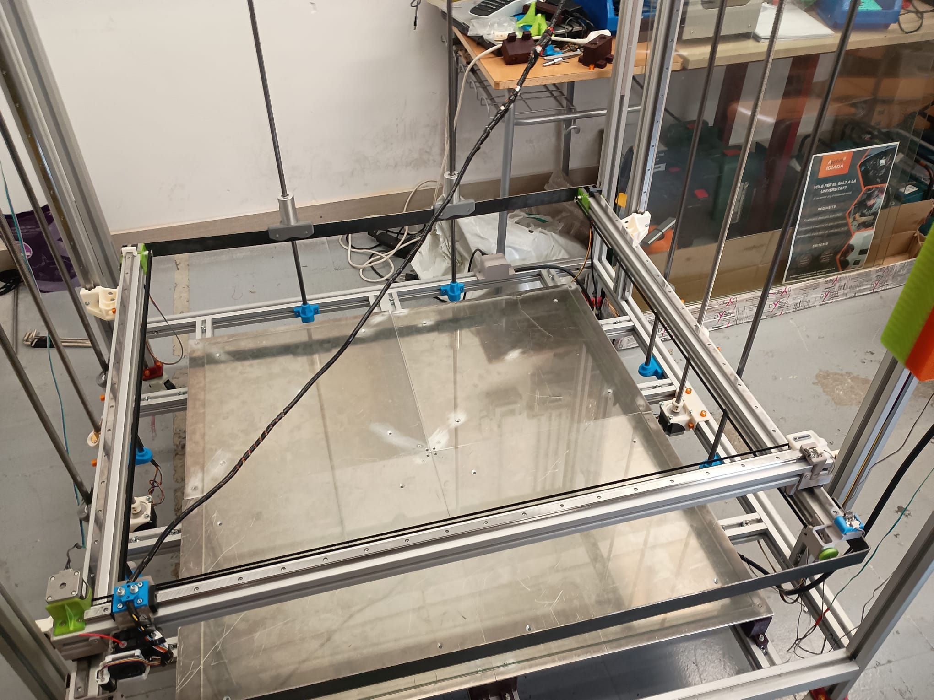
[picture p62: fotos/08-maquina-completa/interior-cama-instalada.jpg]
Interior — cama instalada

*Vista interior desde arriba: cama de cristal provisional instalada sobre el marco inferior. Los cables del eje X recorren la estructura.*

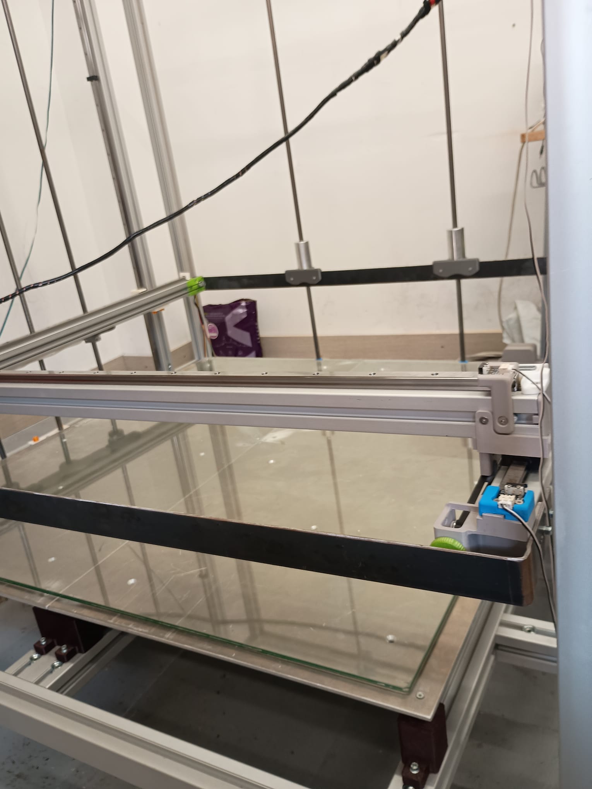
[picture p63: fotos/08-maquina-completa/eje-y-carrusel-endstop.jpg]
Eje Y con endstop

*Carro del eje Y con el endstop (azul) montado y el cabezal de impresión en posición.*

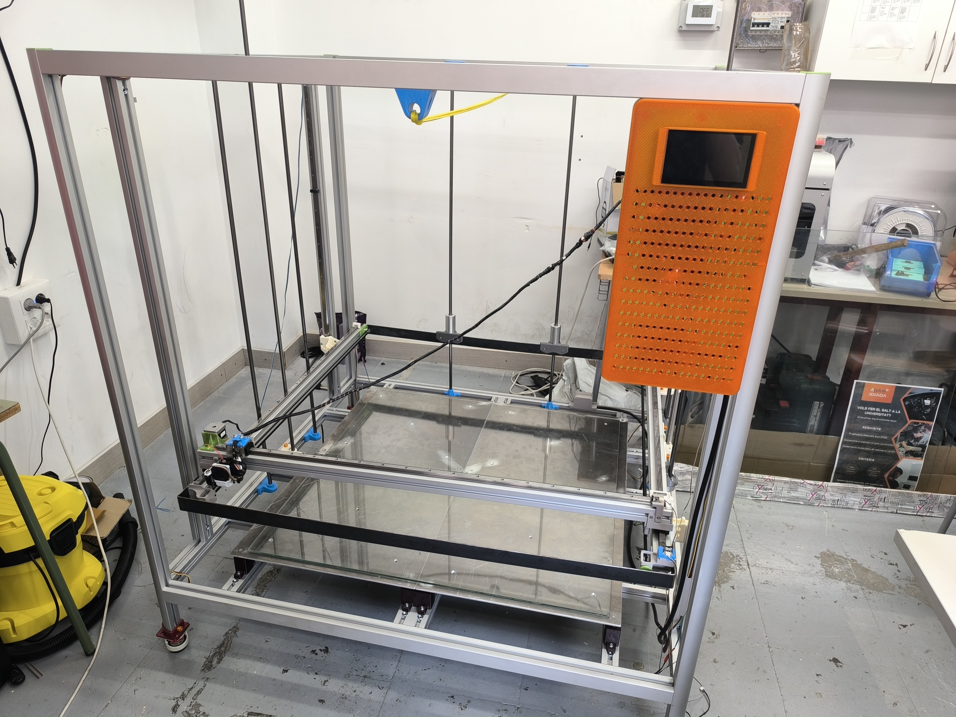
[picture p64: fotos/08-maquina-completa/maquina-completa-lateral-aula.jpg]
Vista desde el aula

*La impresora en el contexto del aula-taller. La escala respecto al mobiliario del instituto muestra el tamaño real de la máquina.*

### Componentes montados en esta fase
- ✅ Marco item 40×80mm completamente ensamblado
- ✅ Guías lineales MGN15R instaladas en X, Y, Z
- ✅ Motores NEMA17 (X, Y×2) y NEMA23 (Z×2) montados
- ✅ Husillos M12 instalados y acoplados
- ✅ Panel de electrónica (Octopus Pro + CB1) instalado
- ✅ KlipperScreen montado en perfil lateral
- ✅ Cama de cristal provisional (para primeras pruebas)
- ✅ Patas niveladoras instaladas
- ⏳ Cama calefactada (4 × 500×500mm) — pendiente instalar

---

## Estado actual

| Sistema | Estado |
|---|---|
| Marco estructura | ✅ Montado |
| Guías lineales MGN15R | ✅ Instaladas |
| Eje X | ✅ Funcionando |
| Eje Y dual (2 motores paralelo) | ✅ Funcionando |
| Eje Z dual (TMC5160 + NEMA23) | ✅ Funcionando |
| Extrusor SO3 | ✅ Funcionando |
| CR Touch + Bed Mesh 5×5 | ✅ Configurado |
| Z_TILT_ADJUST | ✅ Configurado |
| Klipper + Fluidd + KlipperScreen | ✅ Funcionando |
| Cama calefactada (4×500×500mm) | ⏳ Pendiente instalar |
| Archivos 3D de piezas | ⏳ Pendiente subir |

---

## Pendientes

- [ ] Instalar termistor en cama calefactada
- [ ] Instalar 4 × camas calefactadas 500×500mm en paralelo
- [ ] Subir archivos STL/STEP de piezas impresas
- [ ] Completar calibración final (PID cama, Z offset definitivo con `PROBE_CALIBRATE`)
- [ ] Añadir ventiladores en panel de electrónica

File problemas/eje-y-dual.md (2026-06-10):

# Problema: Eje Y — Motor no se movía (cable) + Upgrade a dual motor

## Parte 1: Motor Y no se movía — era el cable

### Descripción

El motor Y (un solo motor inicialmente) no respondía al comando de movimiento. El driver TMC2209 estaba correctamente configurado y el slot de la placa parecía funcionar.

### Diagnóstico

Seguimos el mismo proceso de eliminación que con el slot MOTOR 3:
1. Cambiamos el driver del Y al slot del X → el motor X movía el eje X → **driver OK**
2. Comprobamos las señales del slot Y → señales correctas → **slot OK**

La causa: **el cable del motor Y estaba mal conectado** en el conector JST de la placa.

> «Vale ya lo he arreglado, era el cable efectivamente» — conversación

### Solución

Reconectar el cable del motor Y asegurando que el orden de los hilos (A+, A-, B+, B-) es correcto.

### Lección

Antes de cambiar configuración, **siempre comprueba los cables físicamente**:
- Desconecta y reconecta el conector JST
- Verifica el orden de los hilos (A+, A-, B+, B-)
- Un hilo invertido puede hacer que el motor vibre sin moverse o no responda

---

## Parte 2: Upgrade a doble motor Y en paralelo

### Por qué un motor no era suficiente

Con una cama de **1000mm de profundidad**, el eje Y necesitaba tracción en ambos extremos. Un solo motor en un extremo causaría:
- Flexión del perfil de aluminio en el extremo sin tracción
- Pérdida de pasos en movimientos rápidos
- Posible resonancia/vibración asimétrica

### Solución: 2 motores NEMA 17 en paralelo

Ambos motores se conectan **en paralelo** al mismo slot de driver (MOTOR 2_1), usando el slot MOTOR 2_2 solo como paso físico de corriente (sin configuración propia).

```ini
[stepper_y]
step_pin: PF11    # MOTOR 2_1 — único driver para ambos motores
dir_pin: PG3
enable_pin: !PG5
microsteps: 16
rotation_distance: 40
endstop_pin: ^!PF6
position_endstop: 0
position_max: 1000
homing_speed: 50

[tmc2209 stepper_y]
uart_pin: PC6     # UART del slot MOTOR 2_1
run_current: 1.000  # 1A total = ~0.5A por motor en paralelo
hold_current: 0.500
stealthchop_threshold: 999999
```

> El segundo motor (en slot 2_2) se conecta físicamente en paralelo al primero. No tiene sección propia en printer.cfg porque comparte el driver.

### ¿Por qué no usar 2 drivers independientes (como en Z)?

En Z usamos `Z_TILT_ADJUST` que necesita drivers independientes para mover cada motor de forma diferente y corregir la inclinación de la cama.

En Y **no necesitamos corrección de inclinación** — ambos motores siempre se mueven exactamente igual. Por eso, 1 driver en paralelo es suficiente y más simple.

### Resultado

Con dos motores en paralelo:
- Tracción simétrica en ambos extremos del eje
- Sin pérdida de pasos en movimientos rápidos
- Sin vibración asimétrica

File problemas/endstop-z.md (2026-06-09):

# Problema: Endstop Z de seguridad — Configuración incorrecta

## Descripción del problema

Instalamos un **final de carrera mecánico** en el tope superior del eje Z como parada de emergencia. Si el eje Z sube demasiado (fallo de software o calibración incorrecta), el endstop detiene la máquina para evitar daños.

El problema: **no sabíamos a qué conector de la placa conectarlo**, y varios intentos de configuración no funcionaron.

## La confusión con los conectores

La BTT Octopus Pro tiene varios grupos de conectores que parecen similares:
- Conectores de endstop (STOP) — para los finales de carrera de homing
- Conectores de temperatura (T0–T3) — para termistores NTC
- Conectores de calentador (HE0–HE3) — para hotends

Los conectores T (temperatura) y los STOP (endstop) usan **2 pines** y tienen aspecto similar.

> «No chaval, te estás confundiendo, no vamos a utilizar la zona de STOP sino la de T, porque son de 2 pines» — conversación

> «Claro, caraulo, yo tengo lo siguiente: en J44 la cama que no hay nada, en J45 el extrusor, en J46 el extrusor...» — conversación

### Intentos fallidos

1. **Conectar al endstop STOP** — la Octopus Pro no tiene suficientes slots de STOP libres para añadir un endstop de seguridad extra
2. **Configurar como endstop virtual** — complicaba el homing

## Solución

Usar el conector **T3 (PF7)** — un conector de temperatura libre — como entrada digital para el endstop de seguridad.

Esto se hace con `[gcode_button]` en lugar de `[endstop_pin]`:

```ini
[gcode_button endstop_z_max]
pin: ~PF7           # ~ = pulldown activado. J49 (T3) pin
press_gcode:
  M118 EMERGENCIA - Endstop Z maximo activado
  M112             # M112 = parada de emergencia inmediata
```

`M112` corta el movimiento y desactiva todos los calefactores instantáneamente.

> **¿Por qué `~` (pulldown)?**  
> Se cambió de `^` (pullup) a `~` (pulldown) tras pruebas físicas. Con pullup el pin daba activaciones falsas. Con pulldown (`~`, resistencia a GND interna del STM32) el final de carrera funciona de forma estable.  
> `~` en Klipper = activar resistencia pulldown interna del MCU (STM32H723 lo soporta).

## Cableado

El final de carrera mecánico (2 pines) se conecta a:
- Pin de señal → T3 (PF7)
- GND → GND del mismo conector

```
Octopus Pro T3:
  PF7  ────── Señal endstop
  GND  ────── GND endstop
```

## Resultado

El eje Z se para inmediatamente si el tope superior es alcanzado, sin interferir con el sistema de homing normal.

## Lección

- Los conectores T de temperatura pueden usarse como entradas digitales generales con `[gcode_button]`
- Probar pullup (`^`) y pulldown (`~`) según el cableado físico — en este caso pulldown resultó más estable
- `M112` es la parada de emergencia más segura — no `M0` ni `CANCEL_PRINT`

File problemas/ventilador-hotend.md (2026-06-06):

# Problema: Ventilador del hotend nunca se apagaba

## Descripción del problema

El ventilador del heatsink del extrusor LDO Smart Orbiter v3.0 **nunca se apagaba**, independientemente de la temperatura del hotend.

También ocurrió el problema opuesto: después de calibrar, el ventilador **nunca arrancaba** hasta que se corrigió el pin.

## Diagnóstico

### Parte 1: Pin incorrecto

El ventilador se conectó inicialmente al slot **PG12** de la Octopus Pro. Ese pin no está definido como pin de ventilador PWM en la placa — el comando no tenía efecto.

> «Huy aparece esto, recuerda que el cable está conectado al slot PG12» — conversación

Los slots de ventilador de la Octopus Pro son FAN0–FAN7, con pines específicos. **PG12 no es un pin de ventilador válido.**

### Parte 2: Siempre encendido

Al mover el ventilador al pin correcto (**PD12**, que corresponde a FAN2), el ventilador arrancaba pero **nunca se apagaba**, incluso cuando el hotend estaba frío.

El problema: la configuración inicial usaba `[fan]` (ventilador de capa) en lugar de `[heater_fan]` (ventilador de heatsink controlado por temperatura).

```ini
# INCORRECTO — ventilador de capa, no de heatsink
[fan]
pin: PD12

# CORRECTO — ventilador controlado por temperatura del hotend
[heater_fan hotend_fan]
pin: PD12
heater: extruder
heater_temp: 50.0    # se apaga cuando baja de 50°C
fan_speed: 1.0
```

## Solución

1. Mover el cable del ventilador de PG12 al **FAN2 (PD12)**
2. Cambiar la sección de `[fan]` a `[heater_fan hotend_fan]`
3. Configurar `heater_temp: 50.0` — el ventilador se activa cuando el hotend supera 50°C y se apaga cuando baja de esa temperatura

Combinado con `[idle_timeout]`:
```ini
[idle_timeout]
timeout: 600
gcode:
  TURN_OFF_HEATERS
  M84
```
Al apagar el calefactor, el hotend baja de 50°C → el ventilador se apaga automáticamente.

## Resultado

El ventilador del heatsink funciona correctamente: se enciende al calentar y se apaga al enfriarse.

## Lección

- **`[fan]`** = ventilador de capa (controlado por el G-code de impresión)
- **`[heater_fan]`** = ventilador de heatsink (controlado por temperatura del hotend)
- El ventilador del SO3 es de heatsink, no de capa — debe usar `[heater_fan]`
- Verificar siempre que el pin usado sea un pin de ventilador válido en la placa

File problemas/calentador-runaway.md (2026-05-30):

# Problema: Calentador subía solo a 220°C sin comando

## Descripción del problema

Al encender la impresora, el hotend empezaba a calentarse **solo** sin que se hubiese dado ningún comando. La temperatura subía hasta 220°C de forma autónoma.

> «No, no se para de calentar, ha llegado hasta los 220 grados sin hacer nada» — conversación

## Causa

El pin del calentador (`heater_pin`) estaba configurado en un pin incorrecto. El HE0 (heater element 0) de la Octopus Pro no estaba cableado correctamente:

> «Oye sigo teniendo el mismo problema... B:-99.4 /0.0 T0:74.9 /0.0» — conversación  
> «No se porque pero el HE0 no funciona» — conversación

El problema era que el calentador físico estaba conectado a un pin diferente al configurado en `printer.cfg`. Cuando el pin configurado no coincide con el real, puede quedar en estado activo por defecto.

## Solución

Verificar el cableado físico del calentador:

1. Apagar la impresora inmediatamente
2. Comprobar a qué conector HE (0, 1, 2, o 3) está conectado el calentador del hotend
3. Verificar que `heater_pin` en printer.cfg coincide:

```ini
[extruder]
heater_pin: PA3   # PA3 = HE0 en la Octopus Pro V1.1
```

Mapa de pines HE de la Octopus Pro V1.1:
- HE0 → PA3
- HE1 → PA4  
- HE2 → PA5  (verificar con el manual de la placa)
- HE3 → (verificar)

4. Si el calentador sigue subiendo tras confirmar el pin, revisar si hay cortocircuito en el termistor o en el MOSFET de la placa

## Resultado

Con el pin correcto (`PA3`) y el cableado verificado, el hotend solo calienta cuando se le ordena explícitamente con `M104` o `M109`.

## Lección

**Siempre verificar físicamente a qué pin está conectado cada componente.** La placa tiene múltiples slots similares (HE0, HE1, HE2, HE3) y es fácil conectar en el incorrecto. Una discrepancia entre el cable físico y la config puede causar comportamientos peligrosos.

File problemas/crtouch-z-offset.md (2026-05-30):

# Problema: CR Touch — z_offset obligatorio al arrancar

## Descripción del problema

Al añadir la sección `[bltouch]` a `printer.cfg`, **Klipper no arrancaba**:

```
Option 'z_offset' in section 'bltouch' must be specified
```

## Causa

Klipper exige que el campo `z_offset` esté **siempre presente** en la sección `[bltouch]`, incluso si todavía no lo has calibrado. Si el campo no existe, el servidor Klipper falla al cargar la configuración.

## Solución

Añadir `z_offset: 0` temporalmente para que Klipper arranque:

```ini
[bltouch]
sensor_pin: ^PB7
control_pin: PB6
pin_up_touch_mode_reports_triggered: False
x_offset: 0
y_offset: 0
z_offset: 0        # TEMPORAL — calibrar después con PROBE_CALIBRATE
speed: 5.0
lift_speed: 10.0
samples: 2
sample_retract_dist: 5.0
```

Luego calibrar el offset real con:

```
PROBE_CALIBRATE
```

Klipper baja el CR Touch hasta tocar la cama y te permite ajustar el offset con el comando `TESTZ Z=-0.1` (bajar) o `TESTZ Z=+0.1` (subir). Al terminar, `SAVE_CONFIG` guarda el valor real en el bloque `#*# SAVE_CONFIG` al final del archivo.

## Valor calibrado en nuestra máquina

El `SAVE_CONFIG` guarda automáticamente el offset real. El valor varía según el montaje físico del CR Touch respecto a la boquilla.

## Lección

- Klipper valida toda la configuración al arrancar — un campo faltante impide el inicio
- El `z_offset` en `[bltouch]` es un **placeholder** hasta calibrar — siempre pon `0`
- El valor real queda guardado en `#*# SAVE_CONFIG` — **no editar ese bloque manualmente**

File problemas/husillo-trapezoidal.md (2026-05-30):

# Problema: Husillo trapezoidal métrico 12 de 1200mm — difícil de encontrar

## Descripción

Para el eje Z de 1000mm necesitábamos husillos de al menos **1200mm de longitud** (con algo de margen). La especificación:

- **Tipo:** Husillo trapezoidal / roscado
- **Diámetro:** 12mm (métrica 12)
- **Paso:** 2mm
- **Entradas:** 4 (paso efectivo = 2 × 4 = **8mm por vuelta**)
- **Longitud mínima:** 1200mm

> «Tenemos un problema para encontrar la barilla trapezoidal que soluciones nos das para conseguir una barilla de 1000mm» — conversación

## ¿Por qué este husillo específico?

### Relación con rotation_distance

En Klipper, el parámetro `rotation_distance` para Z se calcula así:

```
rotation_distance = paso × entradas = 2mm × 4 = 8mm/vuelta
```

Un husillo T8 (8mm diámetro, 2mm paso, 4 entradas) también daría 8mm/vuelta, pero con diámetro 8mm se habría doblado en 1m de longitud.

Con **métrica 12** y 1.2m de longitud, el husillo tiene suficiente rigidez para no flectar.

### Por qué 4 entradas y no 1

Un husillo de 1 entrada con paso 2mm daría `rotation_distance = 2`. Esto significa:
- Mucha resolución (bueno)
- Velocidad Z muy lenta (malo — escalar 1m llevaría mucho tiempo)

Con 4 entradas: `rotation_distance = 8`. Velocidad Z máxima de 5mm/s = 5mm/s × 60s = **300mm/min** — manejable.

## Dónde encontrarlo

Proveedores que suelen tener husillos T12 de 4 entradas en 1200mm:
- Proveedores de CNC en España (Servocity, Ooznest)
- Ali Express (envío lento pero mucho stock)
- Tiendas de automatización industrial

> Asegurarse de especificar: **D=12mm, paso=2mm, 4 entradas (4-start), longitud=1200mm**

## Configuración resultante

```ini
[stepper_z]
rotation_distance: 8   # 2mm paso × 4 entradas = 8mm/vuelta
microsteps: 16
```

Con `microsteps: 16`:
```
Resolución = 8mm / (200 pasos × 16) = 0.0025mm = 2.5 micras por paso
```

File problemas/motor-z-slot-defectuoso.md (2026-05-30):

# Problema: Slot MOTOR 3 defectuoso en la Octopus Pro

## Descripción del problema

El eje Z usa **dos motores NEMA 23 independientes** para poder nivelar la cama automáticamente con `Z_TILT_ADJUST`. La configuración inicial asignaba:

- Z izquierdo → MOTOR 1
- Z derecho → MOTOR 3

El Z derecho (MOTOR 3) **no respondía**. El motor no se movía, no había error de Klipper, y el driver parecía funcionar.

## Diagnóstico

Proceso de eliminación:

1. **¿Es el driver?** → Conectamos el TMC5160 del MOTOR 3 al slot MOTOR 1. El motor funcionó. **El driver estaba bien.**

2. **¿Es el motor?** → Conectamos el motor del Z derecho al MOTOR 1. El motor funcionó. **El motor estaba bien.**

3. **¿Es el slot?** → Conectamos un driver diferente al MOTOR 3. El motor seguía sin moverse. **El slot MOTOR 3 de la placa estaba defectuoso.**

> «el driver no es, puesto que he puesto el driver de Y en X y se movía X, quizá es el slot del motor, mira los comentarios de placa» — conversación de proyecto

## Solución

Mover el motor Z derecho al **MOTOR 5** (que estaba libre).

### Cambios en printer.cfg

```ini
# ANTES (con slot defectuoso)
[stepper_z1]
step_pin: PG4    # MOTOR 3 — DEFECTUOSO
dir_pin: PC1
enable_pin: !PA0

# DESPUÉS (con slot funcional)
[stepper_z1]
step_pin: PC13   # MOTOR 5 — FUNCIONAL
dir_pin: !PF0    # ! invertido para girar en la misma dirección que Z
enable_pin: !PF1
```

> **Nota sobre el `!` en `dir_pin`:** Al cambiar de slot, el motor giraba en sentido contrario al Z izquierdo. Añadiendo `!` (inversión) al `dir_pin` se corrige sin necesidad de rehacer el cableado físico.

## Resultado

Ambos motores Z funcionan correctamente con `Z_TILT_ADJUST`, que nivela los dos lados de la cama de forma independiente.

## Lección

**Siempre comprobar el slot antes de asumir que el problema es el driver o el motor.**  
La BTT Octopus Pro puede tener slots defectuosos de fábrica — no es un fallo del usuario.

Si un motor no responde:
1. Prueba el driver en otro slot
2. Prueba el motor en otro slot
3. Si ambos funcionan en otros slots → el slot original está muerto

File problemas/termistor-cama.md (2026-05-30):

# Problema: Termistor de la cama calefactada no instalado

## Descripción

La cama calefactada de 1000×1000mm todavía **no tiene termistor instalado**. Klipper necesita un termistor para controlar la temperatura de la cama, pero sin sensor el sistema no puede leer la temperatura real.

## Solución temporal en printer.cfg

Para que Klipper no bloquee el inicio por un sensor de temperatura inválido, usamos una configuración de parche:

```ini
[heater_bed]
heater_pin: PA1
sensor_type: EPCOS 100K B57560G104F  # termistor genérico como placeholder
sensor_pin: PF3
control: watermark
min_temp: -110   # valor muy bajo para que no falle aunque no haya sensor
max_temp: 130
```

`min_temp: -110` evita que Klipper dé error de "temperatura por debajo del mínimo" cuando el pin de temperatura lee valores fuera de rango (sin termistor conectado).

> **Advertencia:** Esta configuración no es segura para uso real. Sin termistor, Klipper no puede detectar si la cama se sobrecalienta.

## Solución definitiva

Instalar un termistor **NTC 100K** (tipo EPCOS B57560G104F o equivalente) en la cama:

1. Pegar el termistor en la parte inferior de la cama calefactada con cinta de kapton
2. Pasar el cable hasta la electrónica
3. Conectar al pin **PF3** (T0 de la cama en la Octopus Pro)
4. Cambiar `min_temp: -110` a `min_temp: 0` (o el mínimo real)

Después recalibrar el PID de la cama:
```
PID_CALIBRATE HEATER=heater_bed TARGET=60
SAVE_CONFIG
```

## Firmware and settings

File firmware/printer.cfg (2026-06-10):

[mcu]
# Microcontrolador principal - STM32H723
# El serial se obtiene con: ls /dev/serial/by-id/
# Conectar via USB a la BTT Pi/CB1
serial: /dev/serial/by-id/usb-Klipper_stm32h723xx_15000F001051313531383332-if00

[printer]
# Configuración general de la impresora
# Cinemática cartesiana (ejes X/Y/Z independientes)
kinematics: cartesian
max_velocity: 300          # Velocidad máxima de movimiento (mm/s)
max_accel: 3000            # Aceleración máxima (mm/s²)
max_z_velocity: 5          # Velocidad máxima eje Z (mm/s) - lento para precisión
max_z_accel: 100           # Aceleración máxima eje Z (mm/s²)

########################################
# EJE X - MOTOR 0 (TMC2209)
# Driver: TMC2209 en modo UART
# Endstop: final de carrera físico en PF5
# Distancia por vuelta: 40mm (polea GT2 20T)
########################################
[stepper_x]
step_pin: PF13
dir_pin: PF12
enable_pin: !PF14
microsteps: 16
rotation_distance: 40      # 20 dientes × 2mm paso = 40mm por vuelta
endstop_pin: ^!PF5         # T1 - donde está conectado físicamente
position_endstop: 0        # El home de X está en la posición 0
position_max: 1000         # Ancho máximo de la cama en mm
homing_speed: 50           # Velocidad de homing (mm/s)

[tmc2209 stepper_x]
uart_pin: PC4
run_current: 0.600         # Corriente en movimiento (A RMS)
hold_current: 0.300        # Corriente en reposo (A RMS)
stealthchop_threshold: 999999  # StealthChop siempre activo (silencioso)

########################################
# EJE Y - MOTOR 2_1 + 2_2 (TMC2209)
# Driver: UN solo TMC2209 azul en MOTOR 2_1
# Dos motores NEMA en paralelo en 2_1 y 2_2
# Se mueven siempre juntos con un solo driver
# Endstop: final de carrera físico en PF6
# Distancia por vuelta: 40mm (polea GT2 20T)
########################################
[stepper_y]
step_pin: PF11             # MOTOR 2_1
dir_pin: PG3
enable_pin: !PG5
microsteps: 16
rotation_distance: 40      # 20 dientes × 2mm paso = 40mm por vuelta
endstop_pin: ^!PF6         # T2 - donde está conectado físicamente
position_endstop: 0        # El home de Y está en la posición 0
position_max: 1000         # Profundidad máxima de la cama en mm
homing_speed: 50           # Velocidad de homing (mm/s)

[tmc2209 stepper_y]
uart_pin: PC6              # UART del slot MOTOR 2_1
run_current: 1.000
hold_current: 0.500
stealthchop_threshold: 999999

########################################
# EJE Z - CONFIGURACIÓN DUAL (TMC5160-T)
# Dos motores NEMA 23 independientes para
# nivelar la cama automáticamente con Z_TILT_ADJUST
# Driver: TMC5160 rojo de alta potencia en modo SPI
# El endstop físico está reemplazado por el
# CR Touch como sonda virtual de Z
# Tornillo: husillo métrico 12 → rotation_distance: 8
########################################

# MOTOR IZQUIERDO (Slot MOTOR 1)
# Motor principal del eje Z - define los límites
# y el comportamiento del eje completo
# NOTA: Movido desde MOTOR 2_1 para liberar
# ese slot para el eje Y dual
[stepper_z]
step_pin: PG0              # MOTOR 1
dir_pin: PG1
enable_pin: !PF15
microsteps: 16
rotation_distance: 8       # Husillo T12: 2mm paso × 4 entradas = 8mm por vuelta
endstop_pin: probe:z_virtual_endstop  # CR Touch como endstop virtual
position_min: -2           # Permite bajar 2mm por debajo de 0 para calibrar Z offset
position_max: 1000          # Altura máxima de impresión en mm
homing_speed: 10           # Velocidad lenta para precisión en Z (mm/s)

[tmc5160 stepper_z]
cs_pin: PD11               # Chip Select SPI - MOTOR 1
spi_software_miso_pin: PA6
spi_software_mosi_pin: PA7
spi_software_sclk_pin: PA5
run_current: 2.000         # Corriente en movimiento (A RMS) - NEMA 23
hold_current: 1.000        # Corriente en reposo (A RMS)
stealthchop_threshold: 999999
driver_TOFF: 3
driver_HSTRT: 4
driver_HEND: 3

# MOTOR DERECHO (Slot MOTOR 5)
# Motor esclavo del eje Z - sigue al motor principal
# Se mueve independientemente durante Z_TILT_ADJUST
# para corregir el paralelismo de la cama
# NOTA: Slot MOTOR 3 original defectuoso, movido a MOTOR 5
[stepper_z1]
step_pin: PC13             # MOTOR 5
dir_pin: !PF0              # ! invertido para girar en la misma dirección que Z
enable_pin: !PF1
microsteps: 16
rotation_distance: 8       # Mismo husillo métrico 12, paso 2mm × 4 entradas = 8mm/vuelta

[tmc5160 stepper_z1]
cs_pin: PE4                # Chip Select SPI - MOTOR 5
spi_software_miso_pin: PA6
spi_software_mosi_pin: PA7
spi_software_sclk_pin: PA5
run_current: 2.000
hold_current: 1.000
stealthchop_threshold: 999999
driver_TOFF: 3
driver_HSTRT: 4
driver_HEND: 3

########################################
# ENDSTOP DE SEGURIDAD Z MÁXIMO (J49 - PF7)
# Final de carrera en tope superior del eje Z
# Parada de emergencia si el eje sube de más
########################################
[gcode_button endstop_z_max]
pin: ~PF7                  # J49 - pullup activado
press_gcode:
  M118 EMERGENCIA - Endstop Z maximo activado
  M112

########################################
# EXTRUSOR - ORBITER SO3 (Slot MOTOR 4)
# Motor: LDO-36STH20-1004AHG(OBT)
# Termistor: ATC Semitec 104NT-4-R025H42G
# Calentador: 24V 72W cerámico
# Relación de reducción: 7.5:1
# Driver TMC2209 con StealthChop DESACTIVADO
# para máxima respuesta del extrusor
########################################
[extruder]
step_pin: PF9
dir_pin: PF10
enable_pin: !PG2
microsteps: 16
full_steps_per_rotation: 200
rotation_distance: 4.637   # Calibrado para el SO3 (oficial: 4.69)
nozzle_diameter: 0.400     # Boquilla estándar 0.4mm
filament_diameter: 1.750   # Filamento estándar 1.75mm
max_extrude_only_distance: 500
max_extrude_only_velocity: 120
heater_pin: PA3            # Pin del calentador cerámico 24V 72W
sensor_type: ATC Semitec 104NT-4-R025H42G
sensor_pin: PF4
min_temp: 0
max_temp: 300
min_extrude_temp: 170      # No extruye por debajo de 170°C (seguridad)

[tmc2209 extruder]
uart_pin: PF2
run_current: 0.850         # Corriente máxima recomendada SO3 (A RMS)
hold_current: 0.100
stealthchop_threshold: 0   # StealthChop DESACTIVADO - mejor respuesta extrusor

########################################
# VENTILADOR HEATSINK SO3 (Slot FAN2 - PD12)
# Ventilador frameless 24V integrado en el SO3
# Cableado: Rojo → VCC FAN2 / Negro → GND FAN2
# Amarillo (señal PWM) → no conectado
# Se activa automáticamente cuando el
# hotend supera 50°C y se apaga con idle_timeout
########################################
[heater_fan hotend_fan]
pin: PD12
heater: extruder
heater_temp: 50.0          # Temperatura de activación (°C)
fan_speed: 1.0             # Siempre a máxima velocidad cuando activo

########################################
# VENTILADOR DE CAPA (FAN3 - J53 - PD13)
# Ventilador de capa controlado por el slicer
# Se activa con M106 y se para con M107
########################################
[fan]
pin: PD13                  # FAN3 - J53

########################################
# CR TOUCH (Creality ALT04)
# Sonda automática de nivelación de cama
# Reemplaza el endstop físico de Z
# Cableado:
# Azul    → PB7 (sensor_pin)
# Rojo    → GND
# Amarillo→ PB6 (control_pin)
# Negro   → 5V
# Blanco  → GND
########################################
[bltouch]
sensor_pin: ^PB7           # ^ = pullup activado
control_pin: PB6
pin_up_touch_mode_reports_triggered: False
x_offset: 0               # Offset X entre boquilla y sonda - calibrar físicamente
y_offset: 0               # Offset Y entre boquilla y sonda - calibrar físicamente
z_offset: 0               # Offset Z - se calibra con PROBE_CALIBRATE
speed: 5.0                 # Velocidad de sondeo (mm/s)
lift_speed: 10.0           # Velocidad de subida entre sondeos (mm/s)
samples: 2                 # Número de muestras por punto para mayor precisión
sample_retract_dist: 5.0   # Distancia de retracción entre muestras (mm)

########################################
# HOMING SEGURO CON CR TOUCH
# Hace home en XY primero, luego baja Z
# con el CR Touch en el centro de la cama
########################################
[safe_z_home]
home_xy_position: 500, 500 # Centro de la cama 1000x1000
speed: 100
z_hop: 10                  # Sube 10mm antes de moverse (seguridad)
z_hop_speed: 10

########################################
# MALLA DE NIVELACIÓN (BED MESH)
# Mapea las irregularidades de la cama
# y las corrige automáticamente al imprimir
########################################
[bed_mesh]
speed: 100
horizontal_move_z: 5
mesh_min: 30, 30
mesh_max: 970, 970
probe_count: 5, 5          # Cuadrícula 5x5 = 25 puntos de sondeo
mesh_pps: 2, 2
algorithm: bicubic         # Interpolación para superficies complejas

########################################
# SENSOR DE FILAMENTO SO3
# Detecta agotamiento de filamento y pausa
# la impresión automáticamente
# Cableado:
# Marrón (FS)  → PG11 (filament switch)
# Gris   (FTU) → PG10 (filament unload button)
########################################
[filament_switch_sensor sensor_filamento]
switch_pin: ^PG11
pause_on_runout: True
runout_gcode:
  M118 Filamento agotado - pausando impresión
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

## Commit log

2026-05-30 feat: documentacion completa impresora 3D 1000x1000mm
    - README con specs, fotos e indice completo
    - hardware/: componentes BOM, placa Octopus Pro, motores-drivers
    - hardware/cableado/: 6 archivos (X, Y, Z, extrusor, CR Touch, cama)
    - firmware/: printer.cfg comentado, klipper-setup, calibracion
    - problemas/: 8 problemas reales con causa + solucion
    - diario/: cronologia del proyecto
    - fotos/: 21 fotos organizadas
    [printer.cfg]
2026-05-30 feat: expand docs + 35 new photos + wiring diagram + materials list
    - README rewritten: correct project history, all new photos indexed
    - diario/progreso.md: full chronological guide Feb→May 2026
    - hardware/lista-materiales-estructura.md: BOM with quantities
    - hardware/piezas-impresas.md: 3D printed parts catalog
    - hardware/cableado/diagrama-general.md: full wiring diagram ASCII
    - fotos/00-prototipo-inicial/: 8 photos from Feb 25 2026 (first inspection)
    - fotos/01-estructura/: 2 new (cable harness, motor bracket)
    - fotos/02-electronica/: 5 new (thermistor cable, CR Touch, motors)
    - fotos/03-piezas-impresas/: 6 new (all printed parts)
    - fotos/05-montaje-electronica/: 4 new (Fluidd running,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
2026-05-31 feat: add 17 new photos from Fotos 3 + update docs
    - 17 categorized photos: board closeups, printed parts, wiring, Fluidd setup
    - placa-octopus-pro.md: STM32H723 closeup + vista superior limpia
    - piezas-impresas.md: 6 new photos (NEMA23 brackets, cross joints, tensors)
    - diario/progreso.md: Fluidd config error screen + full KlipperScreen setup
    - cableado/crtouch.md: CR Touch first connection photos
    - cableado/extrusor.md: labeled cable harness photos in machine
2026-05-31 fix(printer.cfg): correct Z motor values from actual chat history
    - stepper_z1 rotation_distance: 8 -> 7.80 (empirically calibrated)
    - tmc5160 run_current: 2.000 -> 1.200 (real tested value)
    - tmc5160 hold_current: 1.000 -> 0.600 (real tested value)
    Source: conv 08ea335d msg 312 (last message, summary of final state)
    [printer.cfg]
2026-05-31 fix(printer.cfg): revert Z values to correct final state
    - stepper_z1 rotation_distance: 7.80 -> 8 (7.80 was a chat error, never applied)
    - tmc5160 run_current: 1.200 -> 2.000 (SD card version was most recent)
    - tmc5160 hold_current: 0.600 -> 1.000
    [printer.cfg]
2026-05-31 fix(printer.cfg): restore exact config as pasted by user (source of truth)
    Content matches what user had running on the machine.
    position_max corrected to 1000 (user confirmed change was saved).
    SAVE_CONFIG block with real PID: kp=22.602 ki=1.408 kd=90.690
    [printer.cfg]
2026-05-31 add: printer.cfg in root for easy SD card restore
    [printer.cfg]
2026-05-31 fix(printer.cfg): two real corrections from chat history
    - endstop_z_max: ^PF7 -> ~PF7 (pulldown, not pullup — confirmed working in chat)
    - add [fan] pin: PD13 (FAN3/J53 layer fan — was missing entirely)
    [printer.cfg]
2026-05-31 fix: correct technical errors flagged by classmate review
    - NEMA23 Z justification: gantry lifts (not bed — bed is static)
    - Y dual motor reason: lateral stability, not "to travel distance"
    - Piezas materials: PLA → PETG (non-critical) / ASA+ABS (critical)
    - Soportes NEMA23 label: Z → ejes X e Y
    - Render extrusor: remove false SO3 claim
    - Cama calefactada: not installed; solution = 4× 500×500mm beds
    - placa-octopus-pro: replace fake local PDF link with official URL
2026-06-01 feat: second round of classmate corrections + new content
    Corrections from audio review:
    - piezas-impresas: "juntas cruzadas" → conectores metálicos de perfil + photos
    - piezas-impresas: render extrusor → render sistema tensado correas
    - lista-materiales: tornillería M5 → M4/M3; cama 1x1000² → 4×500² beds
    - diario/progreso: remove "juntas cruzadas" reference + M5 fasteners
    - placa-octopus-pro: arquitectura MCU+CB1 explained; power bridge note
    - overview.md: power bridge clarified + future relay note
    New content added:
    - overview.md: crimpado de cables section + Wirefy tool photo
    - piezas-impresas: ruedas niveladoras + mejoras futuras (policarbonato + imanes)
    - calibracion.md: c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
2026-06-02 feat: wiring session + team page + item plans + logo + future projects
    - README: logo IJH, restructure guide-first, item profiles, SO v3.0 fix
    - equipo.md: professors (Fèlix Garcia, Héctor Zazo, Raquel Muñoz), students
    (Simeon Crasiuc, Pau Arias March, Daniel Roselló Díaz), director thanks
    - futuro.md: 15 future projects from audio (encoders, CE cert, chains, etc.)
    - hardware/planos-estructurales.md: item brand, art. 0.0.669.99, 40x80mm
    - hardware/lista-materiales-estructura.md: item 40x80 (not 2040)
    - diario/progreso.md: Fase 8 wiring session + cable label table
    - assets/logo-institut-jaume-huguet.png: official institute logo
    - fotos/05-montaje-electronica: 9 new photos (panel, drive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
2026-06-02 fix+feat: grammar fixes, team complete, manuals section
    - Remove all "juntas cruzadas" from all docs (audio correction)
    - Fix all "2040" → "item 40×80mm" in progreso.md, componentes.md, piezas-impresas.md, lista-materiales
    - componentes.md: "Orbiter SO3" → "LDO Smart Orbiter v3.0" with box-confirmed specs
    - equipo.md: add Sergio Tenorio Martínez (CAD/planos estructurales)
    - manuales/README.md: official docs for all components (BTT, Klipper, LDO, TMC, CR Touch, item, Fluidd)
    - manuales/BTT_Octopus_pro_EN.pdf: BTT manual included in repo
2026-06-06 feat: complete machine photos + definitive printer.cfg + institute identity
    - fotos/08-maquina-completa: 12 photos of fully assembled printer (05-jun-2026)
    Hero shots: frontal, lateral, interior, bed, KlipperScreen on, classroom context
    - firmware/printer.cfg: definitive config from Simon — cleaned comments, fixed z1
    rotation_distance comment, confirmed ~PF7 pulldown for z_max endstop
    - README: hero shot of complete machine at top, CEFP cycle name, full institute name
    - equipo.md: CEFP Fabricació Additiva 2025-2026, full institute name
    - diario/progreso.md: Fase 9 complete assembly (05-jun), updated state table
    - Institute: Institut Jaume Huguet — Antiga Escola del Treball (full off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
    [printer.cfg]
2026-06-06 fix: final grammar sweep — all SO3/2040/juntas errors cleared
    - hardware/motores-drivers.md: "Orbiter SO3" → "LDO Smart Orbiter v3.0"
    - hardware/cableado/extrusor.md: title + table row updated
    - hardware/componentes.md: "compatibe" → "compatible", SO3 motor ref fixed
    - hardware/piezas-impresas.md: last "perfil 2040" caption → "item 40×80mm"
    - problemas/ventilador-hotend.md: "Orbiter SO3" → "Smart Orbiter v3.0"
    - equipo.md: logo alt text updated with full institute name
    All .md files now free of: juntas cruzadas, 2040, compatibe, Orbiter SO3
2026-06-06 fix(equipo): Héctor Zazo — electrónica/cableado/informática (not mecánico)
2026-06-06 fix: remove L=1400mm from marco spec (per classmate review)
2026-06-09 feat: add 57 STEP files + definitive printer.cfg + cross-repo links
    - hardware/archivos-3d/: 57 STEP files (Sergio Tenorio) extracted from RARs
    - Full assembly: Ensamble Impresora gran formato V4.step
    - Smart Orbiter v3.0 extruder, X/Y/Z axes, heated bed, GT2 pulleys
    - hardware/archivos-3d/README.md: indexed catalog of all 57 files by subsystem
    - firmware/printer.cfg: definitive version (M12 husillo, SO3→Smart Orbiter v3.0, MOTOR5 Z1, correct endstop_z_max pin ~PF7)
    - hardware/piezas-impresas.md: updated archivos-3d section with real links
    - README.md + equipo.md: cross-repo links to CA and EN versions
    [4010 turbo fan Creality DC Brushless CHA4024RM-10B.step, Brazo soporte tensor eje Y.step, CR-Touch-Dummy v1.step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]
2026-06-09 fix: endstop_z_max ^PF7→~PF7 (pulldown) + tmc2209 extruder typo
    - problemas/endstop-z.md: document change from pullup ^ to pulldown ~
    on PF7 (J49/T3); explains STM32H723 pulldown support
    - hardware/motores-drivers.md: fix [tmc2209 extrusor] → [tmc2209 extruder]
2026-06-10 feat: actualizar printer.cfg definitivo + pines endstop PF5/PF6
    - printer.cfg: endstop X → ^!PF5 (T1), endstop Y → ^!PF6 (T2)
    - printer.cfg: ventilador de capa → PD13 FAN3 J53
    - printer.cfg: comentarios corregidos (husillo T12, typo 'vaso'→'paso')
    - cableado/eje-x.md: PG6 → PF5, STOP_0 → T1
    - cableado/eje-y.md: PG9 → PF6, STOP_2 → T2
    - cableado/overview.md: tabla endstops + mermaid + FAN3 añadido
    - cableado/diagrama-general.md: ASCII diagram actualizado + FAN3
    - placa-octopus-pro.md: T1=PF5/T2=PF6 correcto, BED=PF3 separado
    [printer.cfg]
2026-06-10 fix: corregir refs PG6/PG9 residuales + T1(PF3)→BED(PF3)
2026-06-10 docs: eliminar atribución individual — trabajo en equipo
2026-06-10 docs: eliminar printer.cfg raíz obsoleto + limpiar refs individuales en futuro.md
    [printer.cfg]
